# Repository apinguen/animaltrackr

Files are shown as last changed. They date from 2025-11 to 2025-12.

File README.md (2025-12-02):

# animaltrackr
A primarily 3d-printed turret capable of tracking, taking pictures of, and (eventually) identifying passing wildlife. Also has a watergun feature for anti bird/cat poop feature.  
Features:
 - 360 degree yaw/20ish degree pitch movement of the water squirter/camera
 - Motion tracking - Day/night picture taking
 - Water gun for deterrence
 - LCD menu controlled by two buttons/joystick
 - Motion detection through PIR sensor
 - *Theoretically* self-sufficient given enough sun

*Note about cart The BOM lists the regular non-discounted prices of the items
*Note about hours: This was essentially my first major project in Onshape, so the whole process likely took me a lot more time than what someone already proficient in Onshape would take.

Onshape Link: https://cad.onshape.com/documents/f6ea7a198ba9f9fc6b63369a/w/d75fd0cdbd946a41c70640fd/e/8d568dd9e65cdeb0643e5bf5













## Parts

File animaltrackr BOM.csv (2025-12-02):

Name | Details | Link | Unit Price | Quantity | Total Price | Running Total | Percentage of Total | Total Price
Raspberry Pi Zero |  | https://www.microcenter.com/product/502843/raspberry-pi-zero-wh-with-pre-soldered-headers | 15.99 | 1 | 15.99 | 15.99 | 17.72% | 90.23
Electric Water Spray Kit 02 |  | https://us.store.bambulab.com/products/electric-water-spray-kit-02?id=42961100177544 | 10.99 | 1 | 11.95 | 27.94 | 13.24%
Micro Servo Motors (2 pcs) 360 Degrees |  | https://www.aliexpress.us/item/3256808426929034.html | 3.18 | 1 | 3.46 | 31.4 | 3.83%
Hot Sell HBVCAM 5MP OV5647 Raspberry Pi Camera Module with Automatic IR-Cut |  | https://www.aliexpress.us/item/3256806071615047.html | 8.25 | 1 | 13.79 | 45.19 | 15.28%
Raspberry pi OV5647 camera Zero adapter FFC special line 15cm |  | https://www.aliexpress.us/item/3256805059340492.html | 1.96 | 1 | 2.13 | 47.32 | 2.36%
304 Stainless Steel Solid Ball Dia 2.0mm SUS Precision Bearing Steel Ball |  | https://www.aliexpress.us/item/3256803905354831.html | 2.11 | 1 | 2.29 | 49.61 | 2.54%
5v 2w Solar Panel |  | https://www.aliexpress.us/item/3256808785442350.html | 18.4 | 1 | 20.01 | 69.62 | 22.18%
5v MPPT Solar Charge Controller |  | https://www.aliexpress.us/item/3256806050084493.html | 5.74 | 1 | 6.24 | 75.86 | 6.92%
PH 2.0 Adapter |  | https://www.aliexpress.us/item/3256805305262265.html | 3.95 | 1 | 4.3 | 80.16 | 4.77%
Male to Female Dupont Connectors |  | https://www.aliexpress.us/item/3256803064350403.html | 7.72 | 1 | 8.4 | 88.56 | 9.31%
RGB LED |  | https://www.aliexpress.us/item/3256805965054405.html | 1.67 | 1 | 1.67 | 90.23 | 1.85%

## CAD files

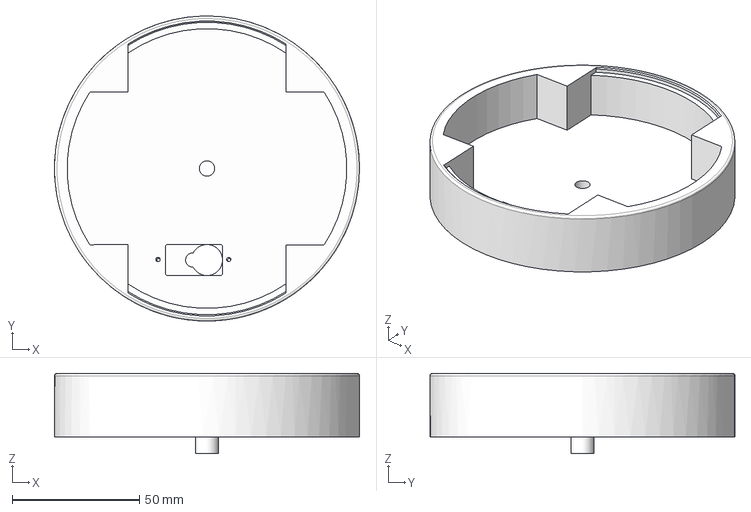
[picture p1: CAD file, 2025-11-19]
cad/Assembly 1 - Turntable.step
120.0 x 120.0 x 31.5 mm

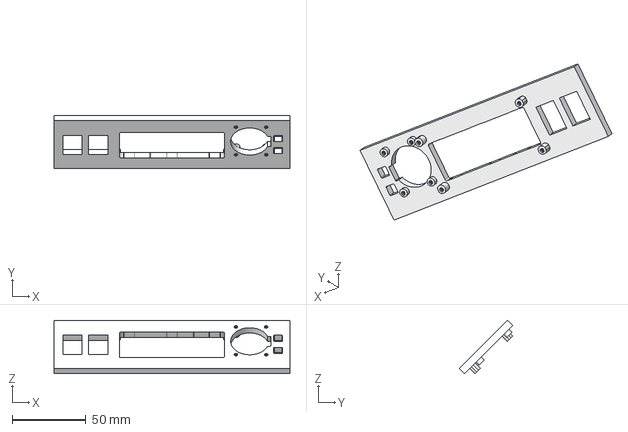
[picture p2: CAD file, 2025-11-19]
cad/Assembly 1 - ControlPanelInner.step
159.8 x 36.1 x 36.1 mm

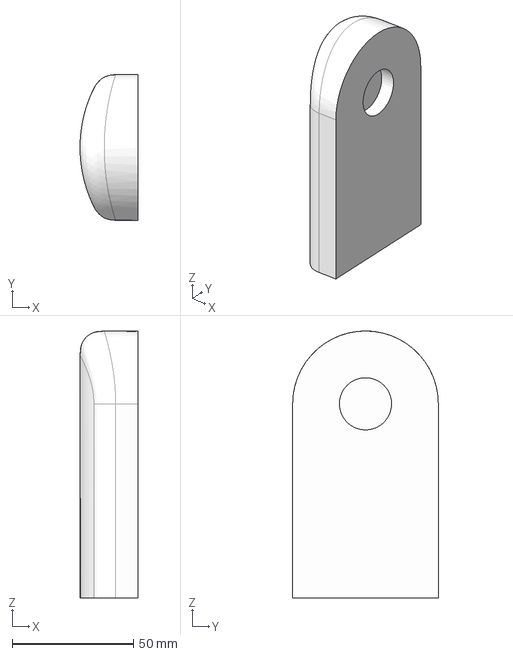
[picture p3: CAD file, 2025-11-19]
cad/Assembly 1 - TurretSideA.step
23.9 x 60.0 x 110.0 mm

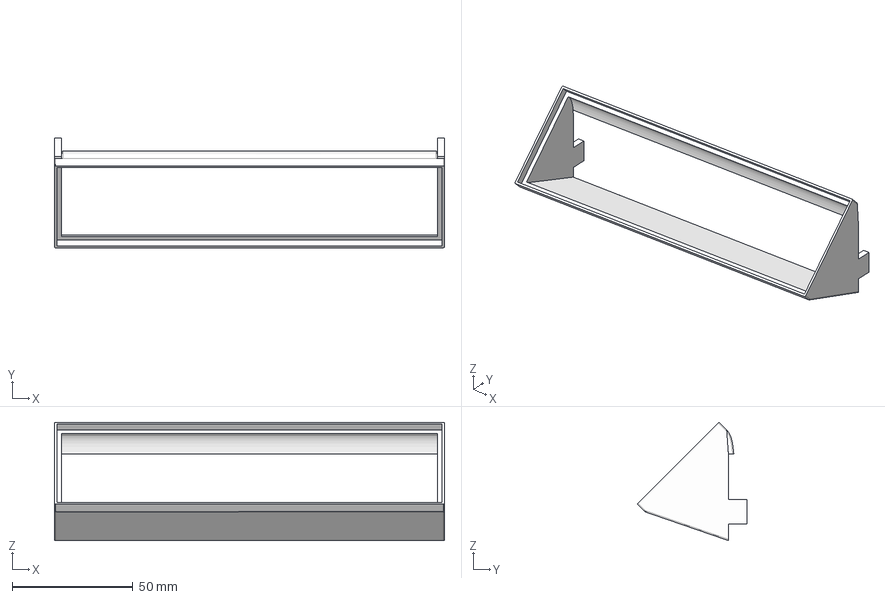
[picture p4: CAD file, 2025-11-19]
cad/Assembly 1 - ControlPanelMount.step
161.8 x 45.5 x 49.1 mm

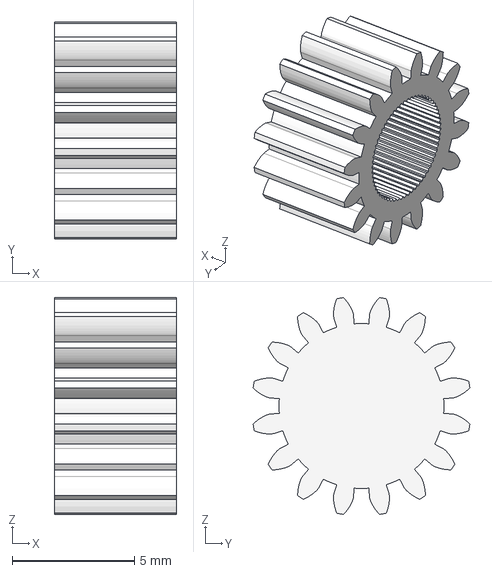
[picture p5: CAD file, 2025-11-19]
cad/Assembly 1 - TurretyGear.step
5.00 x 8.88 x 8.88 mm

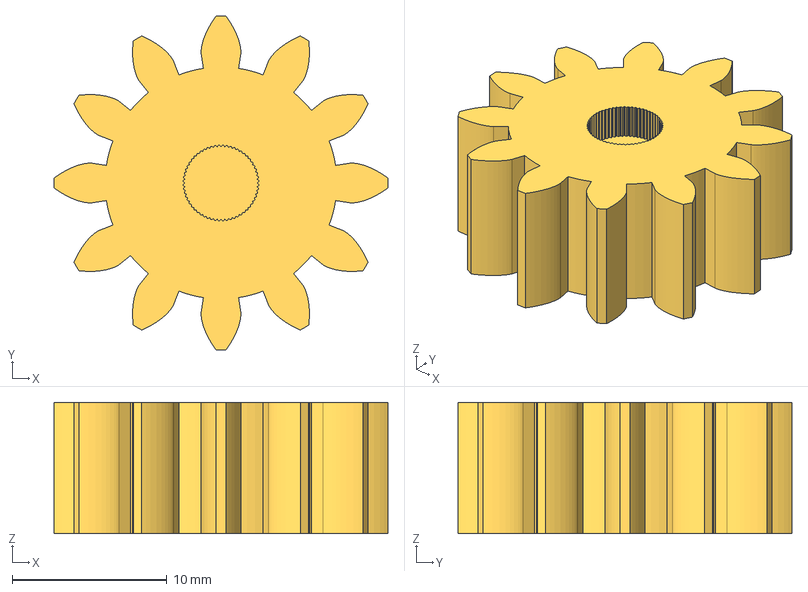
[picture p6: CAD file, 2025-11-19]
cad/Assembly 1 - TurntableGear.step
21.6 x 21.6 x 8.50 mm

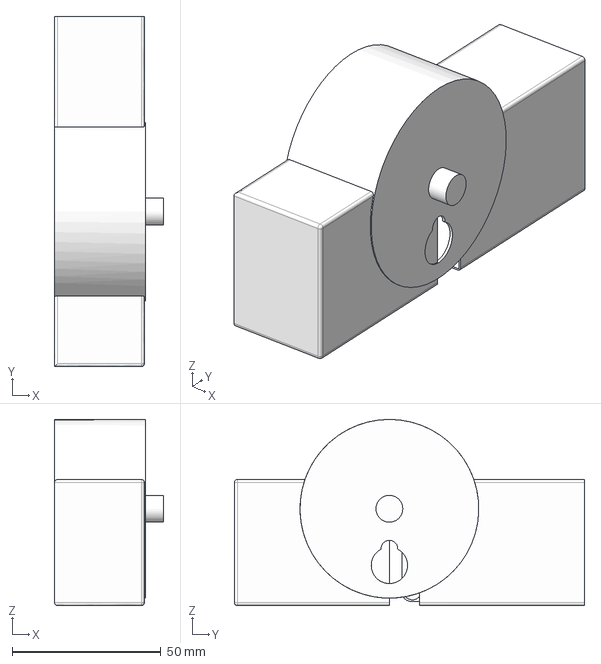
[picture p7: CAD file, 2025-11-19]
cad/Assembly 1 - TurretyBodyB.step
36.5 x 117.5 x 62.5 mm

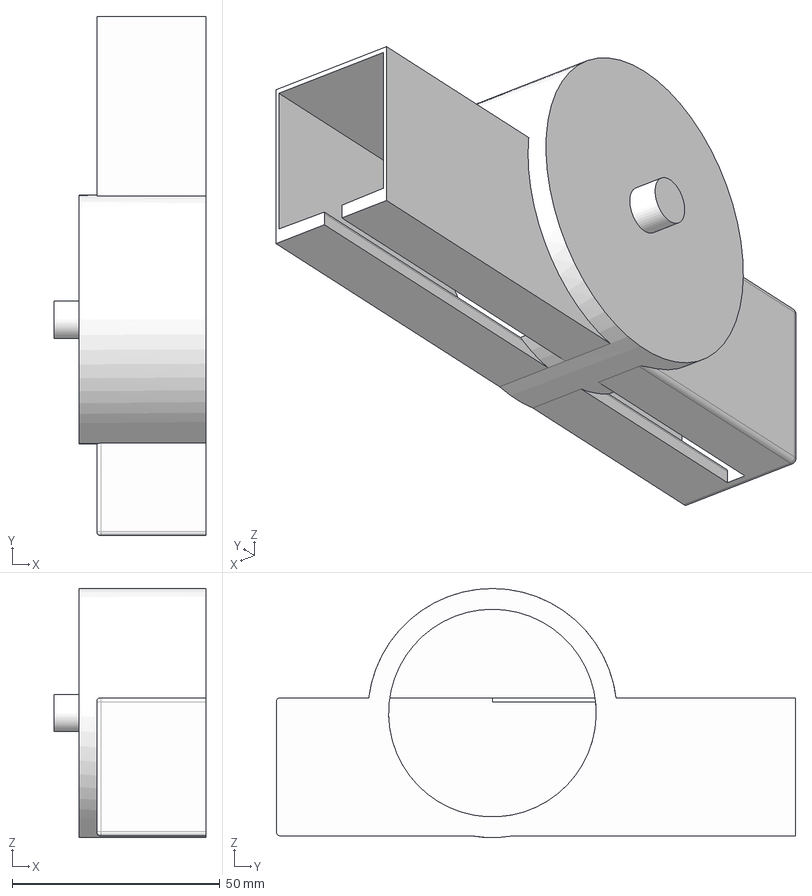
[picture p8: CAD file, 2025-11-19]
cad/Assembly 1 - TurretyBodyA.step
36.5 x 125.0 x 60.0 mm

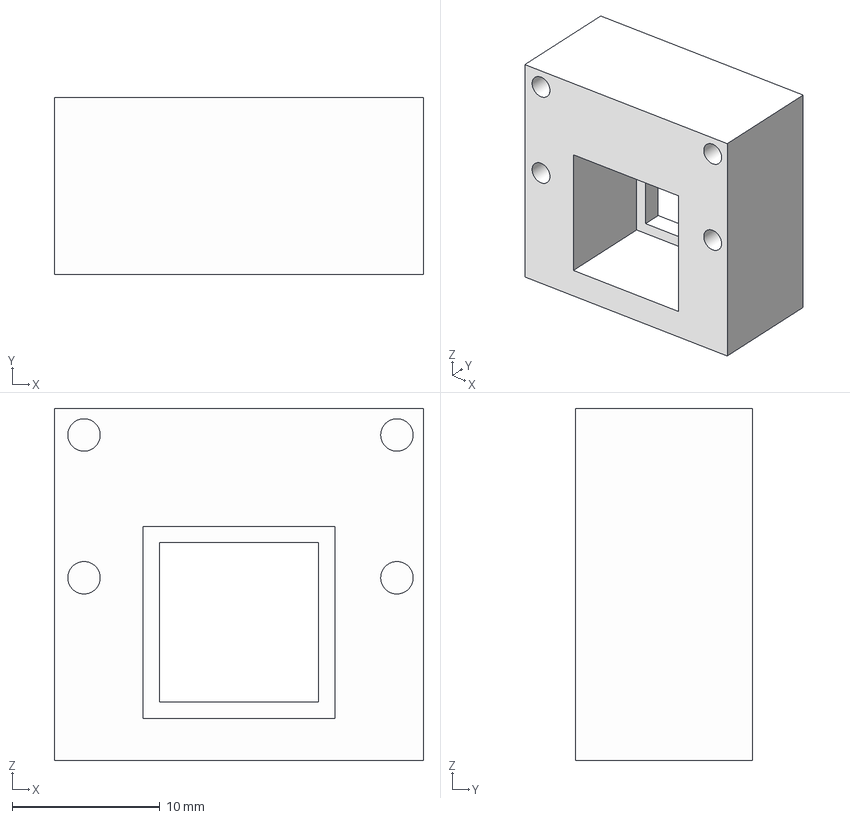
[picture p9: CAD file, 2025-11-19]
cad/Assembly 1 - CameraBlock.step
25.0 x 12.0 x 23.9 mm

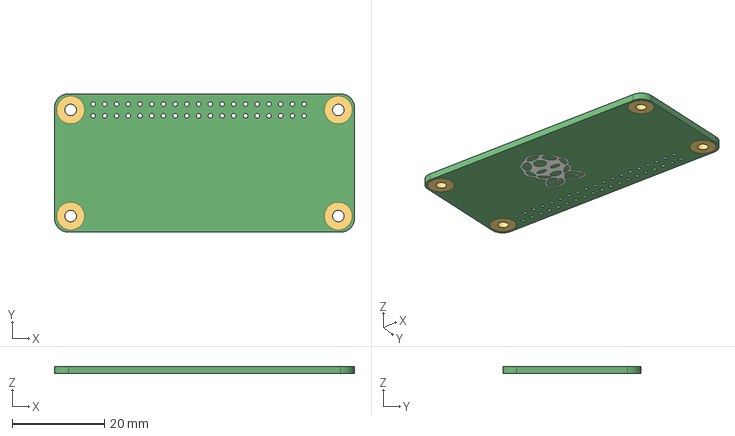
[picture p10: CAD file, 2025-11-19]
cad/Assembly 1 - Board.step
65.0 x 30.0 x 1.62 mm

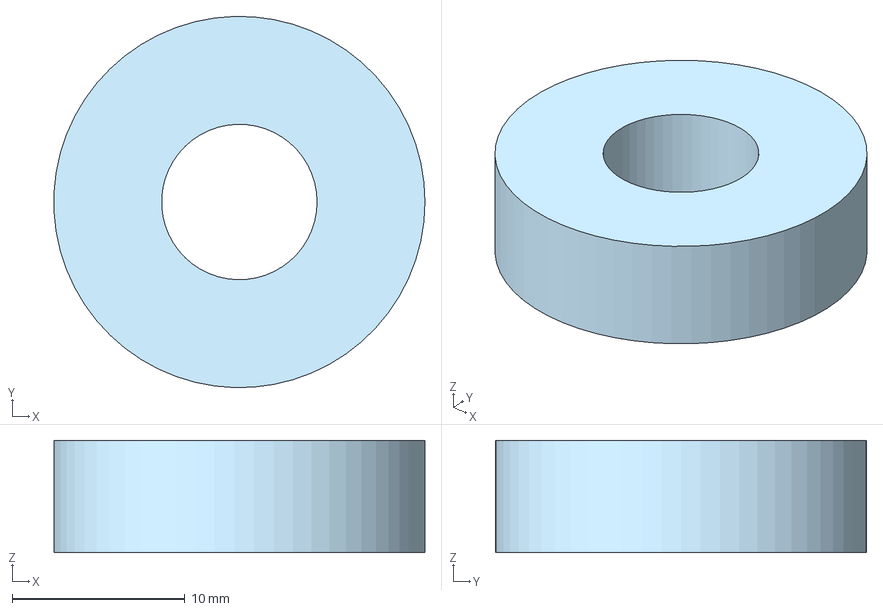
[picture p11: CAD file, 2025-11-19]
cad/Assembly 1 - Bearing.step
21.5 x 21.5 x 6.50 mm

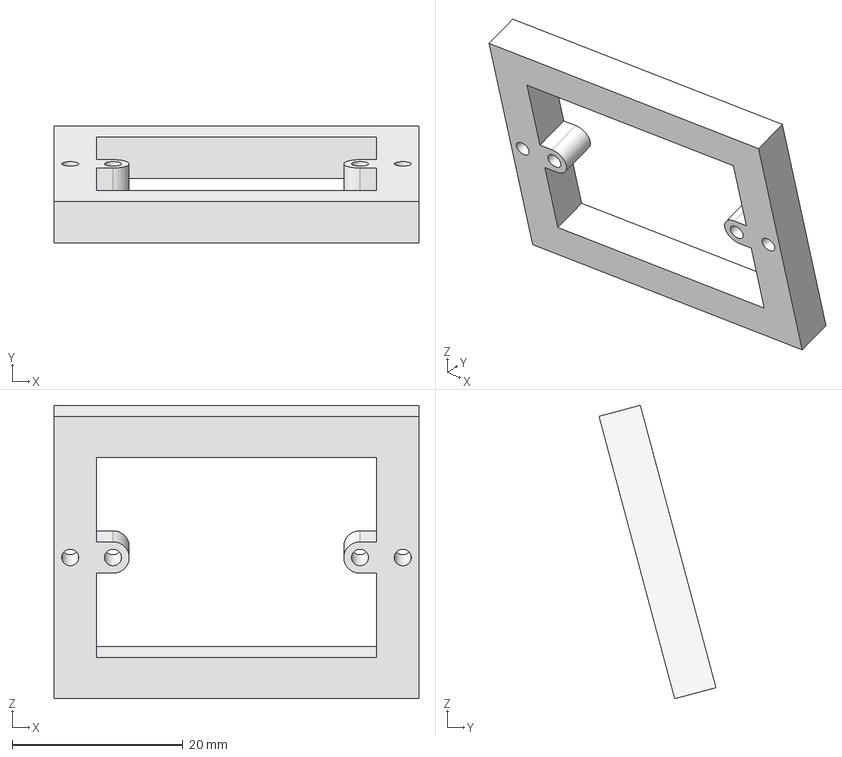
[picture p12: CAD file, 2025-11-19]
cad/Assembly 1 - MotionSensorOuterFrame.step
42.7 x 13.7 x 34.3 mm

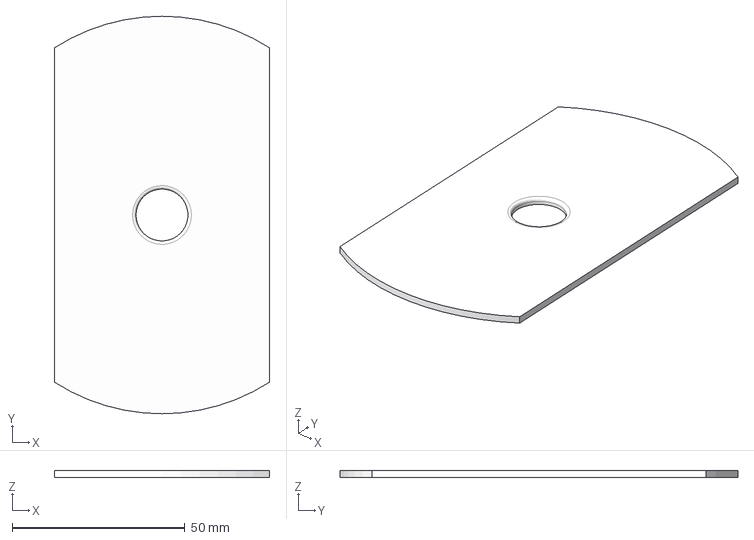
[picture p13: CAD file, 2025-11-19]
cad/Assembly 1 - TurretCover.step
62.2 x 115.0 x 2.00 mm

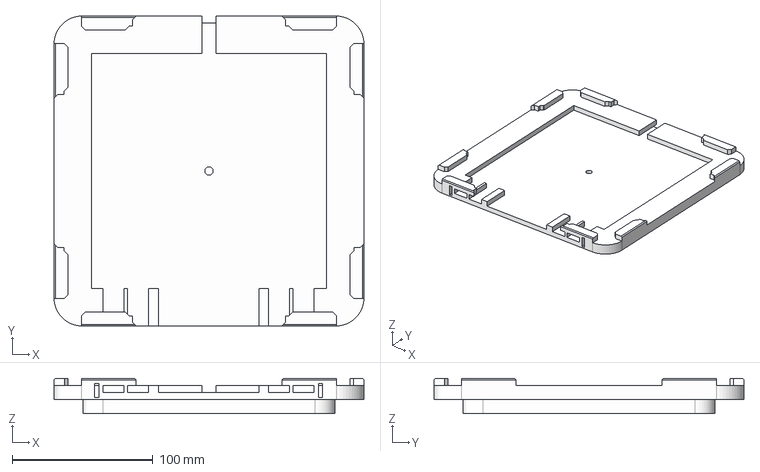
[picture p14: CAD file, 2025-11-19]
cad/Assembly 1 - LidBottom.step
220.0 x 220.0 x 25.0 mm

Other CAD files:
cad/Assembly 1 - BottomButton.step
cad/Assembly 1 - Joystick.step
cad/Assembly 1 - ControlPanelCover.step
cad/Assembly 1 - SquirtyCover.step
cad/Assembly 1 - Base.step
cad/Assembly 1 - CameraCover.step
cad/Assembly 1 - ControlPanelMountInner.step
cad/Assembly 1 - LidTop.step
cad/Assembly 1 - MotionSensorCover.step
cad/Assembly 1 - MotionSensorMount.step
cad/Assembly 1 - PiCover.step
cad/Assembly 1 - TopButton.step
cad/Assembly 1 - TurretSideB.step
cad/STL.stl

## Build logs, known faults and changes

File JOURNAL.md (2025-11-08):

<!--
  ===================    !!READ THIS NOTICE!!   ====================
  DO NOT edit this file manually. Your changes WILL BE OVERWRITTEN!
  This journal is auto generated and updated by Hack Club Blueprint.
  To edit this file, please edit your journal entries on Blueprint.
  ==================================================================
-->

## 10/22/2025 9 AM - Origin of Idea  

For around a year now, I've had the idea to build some sort of device to repel cats from my front lawn. In my neighborhood, there are people who let their cats simply roam around, so there often ends up being cat on the lawn. Of course, something like motion-activated sprinklers are a thing, but where's the fun in that? An idea that I've had in the back of my mind was to create a turret-like device to detect cats using some sort of AI image recognition and spray some water at them to make them not poop on the lawn.
After finding out about Blueprint, this seemed like the perfect opportunity to finally design this, where I would able to potentially get funding for the parts needed. While looking at AI datasets and methods for cat detection, I came across animal datasets that are traditionally used for the classification of wildlife captured on wildlife cameras. I figured that since I was already planning to build a setup that was essentially like a wildlife camera, why not give it that capability?!



Cat picture for your enjoyment

## 10/22/2025 10 AM - The Plan  

**Note that every effort possible will be made to ensure that cats/other animals are not harmed, just discouraged from pooping on the lawn. I love animals and don't want to hurt them; This project is not meant to do that.**

General Capabilities/Features
Should be able to:
- Mechanism placed on a turret base capable of moving in all directions
- Have two cameras, one for day and one for night
- Night vision
- Motion detection of some sort to only turn the camera on when needed, saving battery
- Options for direct and battery power
- Store photos locally
- Water gun feature
- Ability to classify animals in real time

It would be cool if it:
- Solar-powered to make it self-sustaining or at the very least extend the battery life
- Water/weatherproof
- Detect humans ;)
- Automatically upload photos to another computer through wifi
- It could point towards cats
- Some sort of algorithm to only target cats on the lawn
- Image processing can be done locally on the device instead of an external computer


Another cat picture  

## 10/22/2025 1 PM - Research  

Now that the initial ideas are done, I've been researching a lot since I'm new to a lot of this stuff-electronics in general, CADding something from scratch in Onshape, working with Raspberry Pis/Arduinos, etc.
Some stuff I came across:
Turret inspirations
[This super cool 3d-printed watergun turret](https://makerworld.com/en/models/1409374-remote-controlled-water-turret?from=search#profileId-1462873)


[A remake of the turret from Mark Rober's Hack Pack](https://makerworld.com/en/models/1321679-ir-turret-crunchlabs-io1-ver?from=search#profileId-1358024)


[Mini ball turret for model B-17](https://www.thingiverse.com/thing:2229968)


Animal Classification
I plan to use [MegaDetector](https://github.com/agentmorris/MegaDetector), a model trained on camera trap images and already in use by many organizations that track animals, so it should be perfect for the job. However, it only recognizes animals, and classification will be done by [CameraTrapAI](https://github.com/google/cameratrapai), AI models trained specifically for camera traps.

Hardware
- Servos will be used for the turret motion
- Processing will likely done with a Raspberry Pi, unless an Orange Pi is necessary for the image processing
- I already have an Arduino at home, so I'll see if I can maybe integrate that into the design

Resources I found for trail/trap cameras with a Raspberry Pi:
[https://pestpunch.com/raspberry-pi-pest-camera-trap/](https://pestpunch.com/raspberry-pi-pest-camera-trap/)
[https://projects-raspberry.com/trail-camera/](https://projects-raspberry.com/trail-camera/)
[https://projects-raspberry.com/whats-destroying-my-yard-pest-detection-with-raspberry-pi/](https://projects-raspberry.com/whats-destroying-my-yard-pest-detection-with-raspberry-pi/)



_Yet another cat picture :)_

## 10/22/2025 7 PM - Going down the rabbit hole of hardware  

It's been certainly a journey looking through what hardware to use...
With some research/consulting AI, it seems feasible to use a Pi Zero for the main processing, which is also a lot cheaper than the alternative of a full Pi. Though there will be some latency for the processing, a few seconds to identify the animal should be quick enough.

For the water spraying function, I looked over many different pumps and sprayers to find a cheap option. Interestingly, the water gun kit that Bambu Labs sells was relatively cheap compared to other options, and its reliability can be confirmed online, as opposed to sketchy ones on Ali Express. It also beats having to buy a full water gun and then disassemble it. The kit, for only 10.99, also comes with a battery so I don't have to run it on the Pi's power.

Cameras
A lot of resources online used the Raspberry Pi AI Camera, which can essentially run detection models on the camera itself, so the Pi itself doesn't have to do that work. It's just a litteee pricey at upwards of $70 a unit.
I then looked into the normal Pi Camera Module 3s, which seemed more budget friendly while promising the high quality needed for the capture and detection of animals. After a while of searching and reading Reddit about how IR filters work with cameras, if I was to have both night and day animal detecting capabilities, those wouldn't work.
Arducams were another option I considered, with motorized IR-CUT filters to automatically switch between day and night modes, but they lacked the quality needed for MegaDetector, in addition to the lack of many other essential features like autofocus. A similar option was available through PiHut, but again, it lacked the capabilities required.
As of right now, it seems that using two cameras, one with IR and one without might work the best.



ฅ^•ﻌ•^ฅ

## 10/23/2025 7 AM - More hardware research  

So apparently it's a pain to connect two cameras to a Pi Zero.

This thing, to connect 4 cameras (the two camera one was discontinued), is almost $60. Yay.

Originally I was planning to get another Pi Zero and use that, but the cost of everything is adding up to a lot, and I went back to one of the other ideas I had - using a NOIR camera with an IR filter that can be toggled on and off. Eventually I was able to find a camera with a motorized IR cut filter for a reasonable amount.

This is my first time doing a full scale hardware project, so it took me a while to figure out things that might be considered simple, like how to go about controlling a servo with a Pi. Initially I thought things like a servo controller to run servos, but then I learned that you can just connect it directly. It's that simple.

I also happened to have a motion sensor at home, so I'll be implementing that to conserve battery life.
The next step is to get initial CAD done, and while I have worked with Onshape before, I only have around a beginner level experience, so it'll definitely be a learning experience.


meow.  

## 10/23/2025 5 PM - Starting CAD!  

I started with CADding the base of the turret. It should theoretically be simple and quick, since it's mostly just a box, but that's assuming you have experience CADding, which I do not.
It took me about 1.5 hours of struggling and Google to achieve this result:

It won't win any awards, but it looks okay I guess.
After trying to figure out the best way to integrate the hardware into the design, it seems like keeping everything in the moving part (turret) will be the easiest way to avoid wiring issues and somewhat waterproof the whole design. I found this cool turntable off of Printables that I'll be using for inspiration.
[nerf_turntable_2023-jun-09_05-43-46am-000_customizedview15298840655_png.webp](/user-attachments/blobs/proxy/eyJfcmFpbHMiOnsiZGF0YSI6NDkzMywicHVyIjoiYmxvYl9pZCJ9fQ==--70ac56885d3ed6875d84b85fb0fd6e17631aeff9/nerf_turntable_2023-jun-09_05-43-46am-000_customizedview15298840655_png.webp)



## 10/24/2025 - Working on the turn table  

I'd like to say the CAD went smoothly from earlier, but sad to say, it did not. It took me a while to manage all the different layers of features and modifiers until I came upon this:

The ridge is for the ball bearings I'll be putting in the final product.
I don't know why it took me so long, it probably shouldn't have, but it did.



Seal pic this time

## 10/25/2025 8 PM - Almost done with turntable  

Worked on turntable.
Learned a lot about mates in the process
and discovered the magic of "use" in sketches (before I was manually copying the dimensions of the servo)
and figuring out to integrate a bearing.
Next step is to finally finish the servo mount and start working on mounting everything else/the other degree of freedom for the turret.



This CAD thing is so much more time-consuming than I thought it'd be...  

## 10/25/2025 10 PM - Spinny gear!!  

2025-10-25 22-21-18(1) 
That took too long
A bunch of mate shenanigans and research
Two revolute mates on the turn table -> base and gear -> turn table
Gear relation between them  

## 11/3/2025 - Working on Turret  

Some progress on the turret!
Mostly just getting a layout of the components and getting everything fitting together. I'll be using a large stationary inner gear with a bearing in the middle and a smaller servo gear (attached to moving part) for the up and down motion of the turret.



elephant

## 11/5/2025 - Starting to get closer to the end of CAD (hopefully?)  

Struggling with the use command to copy dimensions of stuff onto sketches.
Eventually found a super cool featurescript to do a similar thing.

Random problems with constraints that I have no idea why happen

### Other random problems I ran into:
- You'll see that between this entry and the last, the gear side of the turret is different-this was because I mixed up the two sides and yeah..
- The pivot point needed to be moved up 3 cm in order to have a full range of motion... which was painful
- I realized that the whole design was about 4x too big, especially for a 3d printer, so I scaled everything down by that, which came with a whole bunch of other problems and a lot of manually changing dimensions since it didn't seem like there was another good alternative

### The CAD is coming along.. it looks like something now.



I've mostly just been getting everything to fit together - encasing the water squirter and camera, getting a pi mount, etc.
Stuff I still need to add:
- IR lights for night vision
- Some kind of switch to have some control over the turret/its power supply
- LEDs for feedback would be cool; I also have a small LCD screen that I can maybe use??
- *Aesthetics*

After that I'll write some base code, and then the project should be ready to ship

## Lesson of the day: fillets are amazing and make every edge look better (most of the time :) )!!
maxresdefault
cats also like fillets  

## 11/7/2025 8 PM - Lofts  


I have finally found a use for the loft feature in my project 
Also kinda convoluted wiring tunnel/passage/whatever you call it, but we'll see if it actually works later
The hours I've spent working on the project since the last entry will be added in the next journal entry  

## 11/7/2025 10 PM - Motion Sensor and IR Lights  

As you can see in the last entry I added on a mount for a PIR motion sensor. It's a bit exposed but I'm planning to cover it with plastic wrap (some people on the SmartThings forums said it was a good and budget friendly idea) for weather protection.

For some reason it took me an hour to add this. Again, my Onshape skills are not great.

I also discovered that the sketch of my base was a bit off so I had to work through a bunch of constraint problems trying to fix that.

It turns out there's more than just slapping on a board of IR lights for the night vision; It took a while to find one with the right specifications, optimal wavelength, etc to use. After that, I just need to mount an LCD screen somewhere, add some LEDs to the turret, and some switches. Should be easy.........

OIP
stuff of nightmares

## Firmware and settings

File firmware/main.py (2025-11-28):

"""Application entry point preserving the original state-machine structure."""

from __future__ import annotations

import logging
import signal
import time
from typing import Any, Dict, Tuple

import constants as const
from camera import Camera
from hardware import Hardware
from inference import InferenceEngine
from menu import InputActions, Menu

logging.basicConfig(level=getattr(logging, const.DEFAULT_LOG_LEVEL, logging.INFO))


class Application:
    """Coordinates hardware, camera, and inference via a match-based state machine."""

    def __init__(self) -> None:
        self.hw = Hardware()
        self.camera = Camera()
        self.engine = InferenceEngine(const.MODEL_PATH)
        self.menu = Menu()
        self.menu.mode = const.MODE
        self.mode = self.menu.getMode()
        lines = self.menu.getMessage()
        if len(lines) < 2:
            lines = lines + [""] * (2 - len(lines))
        self._menu_lines: Tuple[str, str] = (lines[0], lines[1])
        self.state = const.State.IDLE
        self._running = True
        self._motion_detected = False
        self._current_yaw = 90.0
        self._current_pitch = 90.0
        self._sweep_direction = 1
        self._next_sweep_time = 0.0
        self._led_cycle = [
            ((True, False, False), "RED"),
            ((False, True, False), "GREEN"),
            ((False, False, True), "BLUE"),
            ((True, True, True), "WHITE"),
            ((False, False, False), "OFF"),
        ]
        self._led_cycle_index = 0
        self._next_led_cycle = 0.0
        self._pitch_direction = 1
        self._next_pitch_step = 0.0
        self._next_pump_test = 0.0
        self._next_sensor_report = 0.0
        self._last_sensor_snapshot: Dict[str, float | bool] | None = None
        self._next_camera_test = 0.0
        self._status_led: str | None = None
        self.hw.when_motion(self._on_motion)

    def run(self) -> None:
        self._setup()
        signal.signal(signal.SIGTERM, lambda *_: self.stop())

        try:
            while self._running:
                self._tick()
        except KeyboardInterrupt:
            logging.info("Interrupted; shutting down")
        finally:
            self._shutdown()

    # ------------------------------------------------------------------
    def _setup(self) -> None:
        try:
            self.hw.setup()
            self.camera.start()
            self.hw.set_servo_angle("yaw", self._current_yaw)
            self.hw.set_servo_angle("pitch", self._current_pitch)
        except Exception:
            self._set_status_led("error")
            raise
        self._set_status_led("idle" if self.hw.has_real_gpio else "error")

    def _tick(self) -> None:
        self._update_menu()
        match self.mode:
            case const.Mode.TUNING:
                self._tick_tuning()
            case const.Mode.DEFAULT:
                self._tick_default()
            case const.Mode.PICTURE:
                self._tick_picture()
            case const.Mode.TURRET:
                self._tick_turret()
            case const.Mode.PICTURE_FIRE:
                self._tick_picture_fire()
            case const.Mode.LED_TEST:
                self._tick_led_test()
            case const.Mode.SERVO_TEST:
                self._tick_servo_test()
            case const.Mode.PUMP_TEST:
                self._tick_pump_test()
            case const.Mode.SENSOR_TEST:
                self._tick_sensor_test()
            case const.Mode.CAMERA_TEST:
                self._tick_camera_test()

    def _tick_tuning(self) -> None:
        logging.debug("TUNING mode idle tick")
        self._idle_wait(0.1)

    def _tick_default(self) -> None:
        logging.debug("DEFAULT mode idle tick")
        self._idle_wait(0.1)

    def _tick_picture(self) -> None:
        if not self._motion_detected:
            self._idle_wait(0.25)
            return
        self._motion_detected = False
        logging.info("PICTURE mode: motion detected, capturing photo")
        self._engage_target(shoot=False, capture=True)
        self._idle_wait(0.25)

    def _tick_turret(self) -> None:
        self._sweep_yaw()
        if not self._motion_detected:
            self._idle_wait(0.05)
            return
        self._motion_detected = False
        logging.info("TURRET mode: engaging motion target")
        self._engage_target(shoot=True, capture=False)

    def _tick_picture_fire(self) -> None:
        self._sweep_yaw()
        if not self._motion_detected:
            self._idle_wait(0.05)
            return
        self._motion_detected = False
        logging.info("PICTURE_FIRE mode: engaging target with photo + water")
        self._engage_target(shoot=True, capture=True)

    def _on_motion(self) -> None:
        logging.info("Motion detected via PIR")
        self._motion_detected = True

    def _update_menu(self) -> None:
        action = self.hw.getInput()
        if action is InputActions.NONE:
            return
        previous_mode = self.menu.getMode()
        self.menu.update(action)
        lines = self.menu.getMessage()
        if len(lines) < 2:
            lines = lines + [""] * (2 - len(lines))
        new_lines = (lines[0], lines[1])
        if new_lines != self._menu_lines:
            self._menu_lines = new_lines
            logging.debug("Menu: %s | %s", new_lines[0], new_lines[1])
            self.hw.display_message(list(new_lines))
        if self.menu.getMode() != previous_mode:
            self.mode = self.menu.getMode()
            logging.info("Mode switched to %s", self.mode.name)

    def _idle_wait(self, duration: float) -> None:
        time.sleep(duration)

    def _sweep_yaw(self) -> None:
        now = time.time()
        if now < self._next_sweep_time:
            return
        self._current_yaw += self._sweep_direction * 2
        if self._current_yaw >= 170:
            self._current_yaw = 170
            self._sweep_direction = -1
        elif self._current_yaw <= 10:
            self._current_yaw = 10
            self._sweep_direction = 1
        self.hw.set_servo_angle("yaw", self._current_yaw)
        self._next_sweep_time = now + 0.2

    def _engage_target(self, *, shoot: bool, capture: bool) -> None:
        frame = self._capture_frame_for_analysis()
        yaw, pitch = self._resolve_target_angles(frame)
        self._set_turret_angles(yaw=yaw, pitch=pitch)

        shooting_error = False
        if shoot:
            self._set_status_led("shooting")
            try:
                self.hw.trigger_gun()
            except Exception:
                shooting_error = True
                self._set_status_led("error")
                logging.exception("Failed to fire water gun")

        if capture and not shooting_error:
            self._capture_photo_with_feedback()
        elif not shoot and not capture and self._status_led != "error":
            self._set_status_led("idle")

    def _capture_photo_with_feedback(self, filename: str | None = None) -> None:
        self._set_status_led("capture")
        self.hw.set_ir_led(True)
        try:
            path = self.camera.capture_photo(filename)
            logging.info("Captured image %s", path)
        except Exception:
            self._set_status_led("error")
            logging.exception("Failed to capture photo")
        finally:
            self.hw.set_ir_led(False)
            if self._status_led != "error":
                self._set_status_led("idle")

    def _capture_frame_for_analysis(self) -> Any | None:
        try:
            for frame in self.camera.frames(frame_limit=1):
                return frame
        except Exception:
            logging.exception("Unable to pull analysis frame")
        return None

    def _resolve_target_angles(self, frame: Any | None) -> Tuple[float, float]:
        target_x, target_y = self._estimate_motion_vector(frame)
        dx = (target_x - const.CAMERA_CENTER[0]) / max(1, const.CAMERA_CENTER[0])
        dy = (target_y - const.CAMERA_CENTER[1]) / max(1, const.CAMERA_CENTER[1])
        yaw = max(0.0, min(180.0, self._current_yaw - dx * 30))
        pitch = max(0.0, min(180.0, self._current_pitch + dy * 20))
        return yaw, pitch

    def _estimate_motion_vector(self, frame: Any | None) -> Tuple[float, float]:
        if frame is None:
            return const.CAMERA_CENTER
        try:
            height, width = frame.shape[:2]
            return (width / 2, height / 2)
        except AttributeError:
            return const.CAMERA_CENTER

    def _set_turret_angles(self, yaw: float | None = None, pitch: float | None = None) -> None:
        if yaw is not None:
            self._current_yaw = yaw
            self.hw.set_servo_angle("yaw", self._current_yaw)
        if pitch is not None:
            self._current_pitch = pitch
            self.hw.set_servo_angle("pitch", self._current_pitch)
        self._idle_wait(const.SERVO_WAIT_TIME)

    def _set_status_led(self, status: str) -> None:
        if status == self._status_led:
            return
        if status == "idle" and not self.hw.has_real_gpio:
            status = "error"
        self._status_led = status
        match status:
            case "error":
                self.hw.set_led(r=True)
            case "shooting":
                self.hw.set_led(r=True, g=True)     # yellow
            case "capture":
                self.hw.set_led(g=True)
            case "idle":
                self.hw.set_led(b=True)
            case _:
                self.hw.set_led()

    # ------------------------------------------------------------------
    # Diagnostic / calibration helpers
    def _tick_led_test(self) -> None:
        now = time.time()
        if now >= self._next_led_cycle:
            color, label = self._led_cycle[self._led_cycle_index]
            self.hw.set_led(*color)
            logging.info("LED test: %s", label)
            self._led_cycle_index = (self._led_cycle_index + 1) % len(self._led_cycle)
            self._next_led_cycle = now + 0.75
        self._idle_wait(0.05)

    def _tick_servo_test(self) -> None:
        self._sweep_yaw()
        now = time.time()
        if now >= self._next_pitch_step:
            self._current_pitch += self._pitch_direction * 4
            if self._current_pitch >= 150:
                self._current_pitch = 150
                self._pitch_direction = -1
            elif self._current_pitch <= 30:
                self._current_pitch = 30
                self._pitch_direction = 1
            self.hw.set_servo_angle("pitch", self._current_pitch)
            logging.info("Servo test: yaw=%.1f pitch=%.1f", self._current_yaw, self._current_pitch)
            self._next_pitch_step = now + 0.25
        self._idle_wait(0.05)

    def _tick_pump_test(self) -> None:
        self.hw.set_led(r=True, b=True)
        now = time.time()
        if now >= self._next_pump_test:
            logging.info("Pump test: firing water gun")
            self.hw.trigger_gun()
            self._next_pump_test = now + 10
        self._idle_wait(0.25)

    def _tick_sensor_test(self) -> None:
        snapshot = self.hw.snapshot_inputs()
        now = time.time()
        if self._last_sensor_snapshot != snapshot and now >= self._next_sensor_report:
            logging.info("Sensor test snapshot: %s", snapshot)
            self._last_sensor_snapshot = snapshot
            self._next_sensor_report = now + 0.5

        if snapshot.get("pir"):
            self.hw.set_led(r=True)
        elif snapshot.get("confirm"):
            self.hw.set_led(g=True)
        elif snapshot.get("back"):
            self.hw.set_led(b=True)
        else:
            self.hw.set_led()
        self._idle_wait(0.1)

    def _tick_camera_test(self) -> None:
        now = time.time()
        if now >= self._next_camera_test:
            try:
                path = self.camera.capture_photo(f"camera-test-{int(now)}.jpg")
                logging.info("Camera test captured %s", path)
            except Exception:
                logging.exception("Camera test capture failed")
            self._next_camera_test = now + 10
        self._idle_wait(0.25)

    def stop(self) -> None:
        self._running = False

    def _shutdown(self) -> None:
        self.camera.stop()
        self.engine.close()
        self.hw.cleanup()


def main() -> None:
    Application().run()


if __name__ == "__main__":
    main()

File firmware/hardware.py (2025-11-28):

"""Hardware abstraction for Raspberry Pi Zero.

This module centralises all direct GPIO / actuator access so the rest of the
application can be unit-tested on non-Pi hosts. When the Pi-specific libraries
are not available, the class transparently falls back to a dry-run mode that
only logs actions.
"""
from __future__ import annotations

import atexit
import logging
import time
from typing import Callable, Dict, List, Tuple
from menu import InputActions

try:
    from LCD import LCD
except ImportError:  # pragma: no cover - optional dependency
    LCD = None  # type: ignore

import constants as const


try:
    import RPi.GPIO as GPIO  # type: ignore
except (ImportError, RuntimeError):
    GPIO = None  # type: ignore

try:
    from adafruit_servokit import ServoKit  # type: ignore
except (ImportError, RuntimeError):
    ServoKit = None  # type: ignore


class Hardware:
    """High-level hardware facade for PIR, LEDs, servos, and the squirt gun."""

    def __init__(self) -> None:
        self._gpio = GPIO
        self._kit = None
        self._pir_callbacks: List[Callable[[], None]] = []
        self._configured = False
        self.backButtonPressed = False
        self.confirmButtonPressed = False
        if LCD is not None:
            try:
                self.lcd = LCD(2, 0x27, True)
            except Exception:  # pragma: no cover - hardware specific init
                logging.exception("Unable to initialise LCD; continuing without display")
                self.lcd = None
        else:
            self.lcd = None
        self.lastMessage = ["", ""]
        atexit.register(self.cleanup)

    # ---------------------------------------------------------------------
    # Setup / teardown
    def setup(self) -> None:
        """Initialise GPIO pins and optional servo driver."""

        if self._configured:
            return

        if self._gpio is None:
            logging.warning("GPIO library not available; running hardware in dry-run mode.")
            self._configured = True
            return

        logging.info("Setting up GPIO pins using BOARD numbering")
        self._gpio.setmode(self._gpio.BOARD)

        for pin in (const.LED_R_PIN, const.LED_G_PIN, const.LED_B_PIN):
            self._gpio.setup(pin, self._gpio.OUT, initial=self._gpio.LOW)

        for pin in (const.GUN_PUMP_PIN, const.GUN_SHOOT_PIN):
            self._gpio.setup(pin, self._gpio.OUT, initial=self._gpio.LOW)

        self._gpio.setup(const.PIR_PIN, self._gpio.IN)

        self._gpio.setup(const.YAW_SERVO_PIN, self._gpio.OUT)
        self._gpio.setup(const.PITCH_SERVO_PIN, self._gpio.OUT)

        self._gpio.add_event_detect(
            const.PIR_PIN,
            self._gpio.RISING,
            callback=lambda channel: self._handle_pir_trigger(),
            bouncetime=200,
        )

        if ServoKit is not None:
            try:
                self._kit = ServoKit(channels=16)
            except Exception as exc:  # pragma: no cover - hardware specific
                logging.warning("Unable to initialise ServoKit: %s", exc)
                self._kit = None
        else:
            logging.info("ServoKit not installed; defaulting to GPIO PWM for servos")
        
        self._gpio.setup(const.BACK_BUTTON_PIN, self._gpio.IN, pull_up_down=self._gpio.PUD_DOWN)
        self._gpio.setup(const.CONFIRM_BUTTON_PIN, self._gpio.IN, pull_up_down=self._gpio.PUD_DOWN)

        self._gpio.add_event_detect(
            const.BACK_BUTTON_PIN,
            self._gpio.RISING,
            callback=lambda channel: self.backButtonCallback(channel),
            bouncetime=200,
        )

        self._gpio.add_event_detect(
            const.CONFIRM_BUTTON_PIN,
            self._gpio.RISING,
            callback=lambda channel: self.confirmButtonCallback(channel),
            bouncetime=200,
        )

        self._gpio.setup(const.IR_LED_PIN, self._gpio.OUT, initial=self._gpio.LOW)

        self._configured = True

    @property
    def has_real_gpio(self) -> bool:
        return self._gpio is not None

    def cleanup(self) -> None:
        """Release hardware resources."""

        if self._gpio is not None:
            try:
                self._gpio.cleanup()
            except Exception:
                logging.exception("Failed to clean up GPIO")
        self._configured = False

    # ------------------------------------------------------------------
    # PIR events
    def when_motion(self, callback: Callable[[], None]) -> None:
        """Register a callback invoked whenever the PIR sensor fires."""

        self._pir_callbacks.append(callback)

    def _handle_pir_trigger(self) -> None:
        logging.debug("PIR trigger received; notifying %d callbacks", len(self._pir_callbacks))
        for callback in self._pir_callbacks:
            try:
                callback()
            except Exception:  # pragma: no cover - defensive programming
                logging.exception("PIR callback raised an exception")
    
    # ------------------------------------------------------------------
    # Button events
    def backButtonCallback(self, channel: int) -> None:
        self.backButtonPressed = True

    def confirmButtonCallback(self, channel: int) -> None:
        self.confirmButtonPressed = True

    def getJoystickDirection(self, tolerance: float) -> Tuple[float, float]:
        """Check the state of the joystick and return its (x, y) direction."""

        if self._gpio is None:
            logging.info("Joystick read (dry-run); returning (0.0, 0.0)")
            return (0.0, 0.0)

        x_val = self._gpio.input(const.JOYSTICK_VRX_PIN)
        y_val = self._gpio.input(const.JOYSTICK_VRY_PIN)

        x_dir = 0.0
        y_dir = 0.0

        if x_val > tolerance:
            x_dir = 1.0
        elif x_val < -tolerance:
            x_dir = -1.0

        if y_val > tolerance:
            y_dir = 1.0
        elif y_val < -tolerance:
            y_dir = -1.0

        return (x_dir, y_dir)

    # ------------------------------------------------------------------
    def set_led(self, r: bool = False, g: bool = False, b: bool = False) -> None:
        """Control the RGB LED."""

        if self._gpio is None:
            logging.info("LED set to R=%s G=%s B=%s (dry-run)", r, g, b)
            return

        self._gpio.output(const.LED_R_PIN, self._gpio.HIGH if r else self._gpio.LOW)
        self._gpio.output(const.LED_G_PIN, self._gpio.HIGH if g else self._gpio.LOW)
        self._gpio.output(const.LED_B_PIN, self._gpio.HIGH if b else self._gpio.LOW)
    
    def display_message(self, lines: List[str] | Tuple[str, str]) -> None:
        """Display a message on the LCD screen."""

        display_lines = list(lines)
        if len(display_lines) < 2:
            display_lines += [""] * (2 - len(display_lines))

        if self.lcd is None:
            logging.info("LCD display (dry-run): %s | %s", display_lines[0], display_lines[1])
            return
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

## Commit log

2025-11-19 Pushed through VS Code because I have no idea how to push files normally to Github
    [Assembly 1 - Base.step, Assembly 1 - Bearing.step, Assembly 1 - Board.step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]
2025-11-21 Framework and stuff
2025-11-28 LED stuff
2025-11-28 Add BOM/update README
    [animaltrackr BOM.csv]
2025-12-02 Wiring Schematics
    [STL.stl, animaltrackr.kicad_pcb, animaltrackr.kicad_sch]
2025-12-02 Interior shots/Schematic
2025-12-02 New BOM
    [animaltrackr BOM.csv]
